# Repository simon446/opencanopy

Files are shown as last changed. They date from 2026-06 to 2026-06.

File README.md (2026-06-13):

# OpenCanopy — Tabletop Automated Pepper Grower

Open-source, zero-config, offline-first tabletop grow unit for a single hot pepper plant.

OpenCanopy is an open-hardware project: a compact, living-room-friendly appliance that keeps one hot
pepper plant healthy indoors with minimal user involvement. It combines a broad-spectrum horticultural
LED, automated pump irrigation with soil-moisture sensing, climate/VPD monitoring, water-safety
interlocks, and a simple LED status interface — all driven by deterministic, fully local **Rust**
firmware (`no_std`, `esp-hal`) on an ESP32-S3.

📖 **Docs site:** <https://simon446.github.io/opencanopy/> · 🧩 **Contributing:** [`CONTRIBUTING.md`](CONTRIBUTING.md) · ⚖️ **Licensing:** [`LICENSES/`](LICENSES/)

The project is built **work item by work item**, organized by engineering discipline. The full
engineering plan and the per-discipline work-item breakdown live in [`plan/`](plan/) — the design
source for the build (engineering spec + work items), tracked alongside the implementation in this repo.

## Project status

- **Repository skeleton, licensing, scope lock, risk register, and CI are in place** (the Project &
  Repo track is complete) — every discipline has a home and quality gates run on each PR.
- **Firmware language: Rust** (`no_std` + `esp-hal`), with a host-testable `control` crate and
  `cargo fmt`/`clippy`/`test` gates in CI.
- The remaining discipline tracks (plant science, firmware, electronics, mechanical, validation, docs)
  follow the work-item breakdown in `plan/`. A spec design review (§23) added pre-order modeling and
  bench-characterization gates and an n=2 parallel grow trial.

## Where things live

| What | Path |
|---|---|
| Documentation (rendered) | <https://simon446.github.io/opencanopy/> |
| Documentation (source) | [`docs/`](docs/) — requirements, scope, risk register, guides |
| Contributing & workflow | [`CONTRIBUTING.md`](CONTRIBUTING.md); issue/PR templates in [`.github/`](.github/) |
| Licensing (per asset type) | [`LICENSES/`](LICENSES/) |
| Implementation subtrees | [`firmware/`](firmware/), [`electronics/`](electronics/), [`mechanical/`](mechanical/), [`validation/`](validation/), [`scripts/`](scripts/) |
| Work items & engineering spec (design source) | [`plan/`](plan/) — engineering spec + per-discipline work items |

## Scope

- **In V1:** one plant, fixed hot-pepper profile, dimmable full-spectrum LED with automated schedule,
  substrate moisture sensing, automated pump watering, reservoir-level + leak safety, temp/humidity
  sensing with VPD, circulation fan, 5-LED status interface, local deterministic firmware, and open
  hardware/firmware/CAD with simulation, hardware-in-loop, and grow-trial validation.
- **Not in V1:** camera/AI plant diagnosis, cloud control, automatic pH/EC dosing, multi-plant
  support, required mobile app, or AC mains inside the unit.

See [`docs/scope.md`](docs/scope.md) for the locked non-goals and [`docs/product-requirements.md`](docs/product-requirements.md)
for the locked physical/hardware envelope.

## Repository layout

The standard open-hardware structure is in place; each subtree has a README describing its purpose:

- `firmware/` — Rust workspace: `control/` (host-testable `no_std` logic), `controller/` (`esp-hal`
  binary), `sim/`, `hil/`.
- `electronics/` — KiCad PCB, wiring, BOM, and electrical verification.
- `mechanical/` — CAD/STEP/STL, drawings, and print settings.
- `docs/` — requirements, scope, risk register, and the guides that ship with V1.
- `validation/` — test plans, measurements, and grow-trial records.
- `scripts/` — tooling (`bom_check.py` §16.3 grow-light gate, `stl_check.py`, calculators).

Full layout: spec §14 (in `plan/`).

## Release gate

V1 is tagged only when the acceptance criteria in the V1 spec (§21, in `plan/`) are all met, as proven
by the Validation & QA track — including an **n=2 parallel grow trial** (design-review decision, §23).

## License

Per-asset open-source licensing — **Apache-2.0** firmware/scripts, **CERN-OHL-S v2** hardware/mechanical,
**CC BY 4.0** docs. See [`LICENSES/`](LICENSES/) and its [mapping note](LICENSES/README.md).

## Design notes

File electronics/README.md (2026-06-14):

# electronics/

PCB, wiring, BOM, and electrical verification for OpenCanopy. Owned by the **Electronics** track
(spec §7, §11, §16).

## Layout

- `pcb/` — custom controller board (designed with the headless tscircuit flow; KiCad retired — [ECO-002](analysis/ECO-002-pcb-toolchain.md)).
  - `netlist/` — **the schematic as data**: `controller_netlist.py` (source of truth — every part +
    pin-level net + ERC checker), generated `controller.net` (optional interchange) and `controller-netlist.csv`.
  - `programmatic/` — **headless code→PCB→Gerbers** flow (tscircuit): the generator, the board, the
    per-subsystem render blocks, and `out/` (draft Gerbers/PnP/BOM + KiCad-PCB bridge + previews).
  - `3d-models/` — checked-in STEP/WRL models of off-the-shelf parts (e.g. the WS2812B-2020 status LED) for mechanical CAD.
  - `fabrication/` — fab notes + stackup (the fab package itself lives in `programmatic/out/`).
- `wiring/` — system harness.
  - `wiring-diagram.svg` — full system wiring diagram.
  - `harness-table.csv` — connector/pin/wire/gauge harness table.
  - `connector-spec.md` — chosen connectors + mating cable-side parts (handoff for mechanical).
- `bom/` — bill of materials.
  - `bom.csv` — primary BOM (must satisfy the §16 constraint list).
  - `alternates.csv` — approved alternate parts.
  - `component-sourcing.md` — real buyable picks for pump / grow light / status LEDs / cables, with
    3D-model sources and the firmware/mechanical/project flags they raise.
- `test/` — electrical verification.
  - `bringup.md` — bench bring-up procedure (WI-EE-08).
  - `pcb-verification.md` — trace/current and thermal verification report (WI-EE-06).
  - `hil-fixture.md` — HIL fixture design + automated fault-test matrix (WI-EE-08).
  - `poc-logs/` — breadboard PoC bench-log templates (WI-EE-01).
- `analysis/` — engineering design/analysis artifacts.
  - thermal budget model + script (WI-EE-10), power budget (WI-EE-02), component PoC plan (WI-EE-01),
    schematic capture + pin map (WI-EE-03), PCB layout design (WI-EE-04) + `design-rules.md` (net
    classes/DRC), status-LED board (WI-EE-09), trace-width calculator, `ECO-001-fan-removal.md`.
    The board layout is generated from the `pcb/netlist/` netlist by the tscircuit flow + these docs.

## Key constraints

ESP32-S3 controller, 24 VDC external certified PSU, electronics in the upper dry bay, locking/keyed
connectors. The grow-light BOM entry must carry real photometric/thermal/electrical data (spec §16.3);
`scripts/bom_check.py` enforces this in CI.

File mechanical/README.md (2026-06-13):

# mechanical/

Frame, bays, mounts, and printable parts for OpenCanopy. Owned by the **Mechanical** track
(spec §8, §12).

## Layout

- `cad/` — design source.
  - `source/` — **parametric build123d model** (Python); see `cad/source/README.md`
    for toolchain + how to regenerate. This is the dimensional authority.
  - `step/` — neutral STEP exports (full assembly + every module), regenerated by
    `cad/source/build.py`.
- `stl/` — printable geometry, regenerated from source.
  - `printable/` — release-quality, manifold STLs intended for end users.
  - `prototypes/` — tolerance coupons / experimental prints.
  - `assembly/` — placed meshes (every part in its assembly position, coarse) used
    by `render.py` and `collision_check.py`; not for printing.
- `drawings/` — orthographic assembly views, generated by `cad/source/drawings.py`.
- `cad-verification-checklist.md` — §12.1 checklist, numbers computed by `verify.py`.
- `bom-mechanical.csv` — mechanical bill of materials (pot, reservoir, frame, …).
- `print-settings.md` — material/zone + slicer settings (PETG/ASA/ABS per §16.2).
- `fit-tests.md` — tolerance-coupon results; feeds calibrated clearances to `params.py`.
- `alpha-build.md` — assembly procedure + alpha build log (M5-09).

## Regenerate artifacts

```bash
.venv-cad/bin/python mechanical/cad/source/build.py            # STEP + STL + placed meshes
.venv-cad/bin/python mechanical/cad/source/verify.py           # §12.1 numbers
.venv-cad/bin/python mechanical/cad/source/collision_check.py  # FCL worst-case interference sim
.venv-cad/bin/python mechanical/cad/source/render.py           # full-assembly sketch renders
.venv-cad/bin/python mechanical/cad/source/drawings.py         # SVG views
.venv-cad/bin/python scripts/stl_check.py --dir mechanical/stl # CI manifold gate
```

The interference sim (`collision_check.py`) runs FCL on the real models with a
configurable printer error margin — see `tolerance-analysis.md`. Multi-angle sketch
renders of the whole build are published to the docs site (`docs/mechanical-build.md`,
images in `docs/assets/renders/`) and refreshed by the Pages CI.

## Key constraints

Open-frame appliance within the **locked 480 × 320 × 700 mm envelope** (see
`docs/product-requirements.md`): electronics in an isolated upper dry bay, water in
the bottom wet bay, removable 10 L pot and 4 L reservoir, leak tray, fan guard, and
stainless fasteners near water (spec §8, §16.2, §17). The model asserts the envelope
and the "water fails downward / electronics live upward" zone separation (§6.2) on
every build.

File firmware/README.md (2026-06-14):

# firmware/

Firmware for the OpenCanopy controller (ESP32-S3), written in **Rust** (`no_std`, `esp-hal`), plus its
host-side simulation and hardware-in-the-loop (HIL) harnesses. Owned by the **Firmware** track. See
spec §9–§10.

This is a Cargo **workspace**. The core control logic is a platform-agnostic `no_std` crate that builds
and unit-tests on the host with stable Rust — no ESP32 and no Xtensa toolchain required to validate
rules (spec §9.1, §10.1). Only the on-target `controller` binary needs the Espressif toolchain.

## Layout

- `Cargo.toml` — workspace manifest (added by the Firmware track, [WI-FW-01](../plan/work-items/02-firmware/WI-FW-01-project-build.md)).
- `rust-toolchain.toml` — pins the Espressif Rust channel (installed via `espup`).
- `.cargo/config.toml` — default target `xtensa-esp32s3-none-elf` + `espflash` runner.
- `control/` — **no_std, platform-agnostic** control logic: state machine, moisture monitor, light,
  climate, LED status, plant profile, and the `hal.rs` sensor/actuator/clock **traits** (the hardware
  seam). V1 is passive (no pump) and fan-less (ECO-003/ECO-001) — the grow LED is the only actuator.
  Builds and `cargo test`s on the host with stable Rust. Has **no** `esp-hal` dependency.
  - `src/`, `tests/`.
- `controller/` — **no_std `esp-hal` binary** for the ESP32-S3; provides concrete trait
  implementations binding `control` to real peripherals.
  - `src/` — `main.rs` plus `sensors/`, `actuators/`, `drivers/`.
- `sim/` — host scenario runner that drives the real `control` crate through simulated trait impls
  (no hardware). See `sim/README.md`.
  - `src/`, `scenarios/`, `models/`.
- `hil/` — hardware-in-the-loop fixtures and procedures for testing on real boards. See `hil/README.md`.
  - `fixtures/`.

## Toolchain

- **Host tests / sim:** stable Rust — `cargo test -p control`, `cargo fmt --check`, `cargo clippy`.
- **On-target build:** install the esp channel with `espup`, then `cargo build` (target set in
  `.cargo/config.toml`); flash/monitor with `espflash`. Xtensa is not on upstream stable Rust, which is
  why host-testable logic is isolated in `control/`.

## Principles (spec §9.1, §10.1)

Control rules are deterministic and offline-first, validated in simulation before any PCB exists, then
re-validated on hardware via HIL. The state machine and fault priorities (§9.3) are encoded as
compiler-checked Rust types. The grow LED (the only actuator) must fail safe (off) on reset/brownout.
Optional Wi-Fi/MQTT telemetry (§9.11) lives behind a default-off Cargo feature, never required for control.

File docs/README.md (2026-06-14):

# docs/

Project documentation for OpenCanopy. These are the human-readable references that ship with V1.

Per spec §14.1, this subtree holds:

| File | Owner track | Purpose |
|---|---|---|
| `product-requirements.md` | Project & Repo | Locked physical envelope and hardware decisions (the design contract). |
| `scope.md` | Project & Repo | V1 scope and explicit non-goals. |
| `risk-register.md` | Project & Repo | Engineering and safety risks, owners, and mitigations. |
| `plant-profile-hot-pepper.md` | Plant Science | Lifecycle stages, setpoints, DLI, watering, VPD, nutrients. |
| `safety.md` | Documentation | Water/electrical, thermal, food-contact, child/pet safety. |
| `assembly.md` | Documentation | Build/assembly guide. |
| `calibration.md` | Documentation | Moisture and pump calibration procedure. |
| `operation.md` | Documentation | Day-to-day operation and grow guide. |
| `troubleshooting.md` | Documentation | Common faults and fixes. |
| `validation-plan.md` | Validation & QA | Dry/wet/grow-trial acceptance plan. |
| `led-status-legend.md` | Documentation | Front-panel LED meaning (state + blink pattern). |
| `maintenance.md` | Documentation | User and developer maintenance schedule. |
| `references.md` | Documentation / Plant Science | Cited sources behind the design decisions. |

The minimum documentation set required before a V1 tag is listed in spec §14.3.

## Engineering & design references (rendered)

Published design docs with renders, one per hardware track:

| Doc | Track | What |
|---|---|---|
| [`electronics-design.md`](electronics-design.md) | Electronics | Controller board: per-subsystem schematics + 3D/board renders, safety design, connectors, BOM, the headless netlist→Gerbers flow. |
| [`mechanical-build.md`](mechanical-build.md) | Mechanical | v1 product-model renders (CAD), joints, conduit, collision/physics checks. |
| [`firmware-api.md`](firmware-api.md) | Firmware | Pointer to the published Rust API docs (`/api`). |

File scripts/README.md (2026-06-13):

# scripts/

Project tooling and calculators for OpenCanopy (spec §14.1). Plain Python, no heavy dependencies, so
they run locally and in CI.

| Script | Purpose | Used by |
|---|---|---|
| `bom_check.py` | Validate `electronics/bom/bom.csv`; fail if a grow light lacks the §16.3 required fields. | CI (WI-PS-06), Electronics |
| `dli_calculator.py` | Convert PPFD ↔ DLI for a photoperiod; estimate delivered PPFD from fixture PPF. **Delivered (`--selftest` in CI).** | Plant Science (WI-PL-02) |
| `pump_calibration.py` | Derive pump on-time ↔ delivered-volume calibration. | Firmware / Validation |
| `moisture_calibration.py` | Map raw capacitive readings to dry/wet calibration points. | Firmware / Validation |
| `log_parser.py` | Parse exported device logs into analyzable form. | Validation |

`bom_check.py` ships with the project-setup track; `dli_calculator.py` ships with Plant Science
(WI-PL-02). The remaining scripts are stubbed by their owning tracks. CI invokes `bom_check.py` and
`dli_calculator.py --selftest` on every PR.

> A reproducible **photometric delivery model** (the §23 DR-01 pre-order PPFD/DLI gate, WI-PL-06) lives
> with the validation track at
> [`validation/ppfd-measurements/model/`](../validation/ppfd-measurements/model/), not here.

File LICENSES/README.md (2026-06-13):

# Licensing

OpenCanopy is multi-licensed **by asset type** — firmware, hardware/mechanical, and documentation
each carry a different open-source license, as recommended in spec §14.2 and locked in §20. Do **not**
collapse these into a single root `LICENSE`; the licenses differ deliberately.

## License files

| File | License | SPDX identifier |
|---|---|---|
| [`firmware-license.txt`](firmware-license.txt) | Apache License 2.0 | `Apache-2.0` |
| [`hardware-license.txt`](hardware-license.txt) | CERN Open Hardware Licence v2 — Strongly Reciprocal | `CERN-OHL-S-2.0` |
| [`docs-license.txt`](docs-license.txt) | Creative Commons Attribution 4.0 International | `CC-BY-4.0` |

## Subtree → license map

This is the authoritative mapping. Every tracked subtree falls under exactly one license.

| Path / asset | License | SPDX |
|---|---|---|
| `firmware/` (all source, tests, sim, HIL) | Apache-2.0 | `Apache-2.0` |
| `scripts/` (project tooling) | Apache-2.0 | `Apache-2.0` |
| `electronics/` (PCB: KiCad source, Gerbers, BOM, wiring) | CERN-OHL-S v2 | `CERN-OHL-S-2.0` |
| `mechanical/` (CAD source, STEP, STL, drawings) | CERN-OHL-S v2 | `CERN-OHL-S-2.0` |
| `docs/` (all documentation) | CC BY 4.0 | `CC-BY-4.0` |
| `README.md`, `CONTRIBUTING.md`, top-level prose | CC BY 4.0 | `CC-BY-4.0` |
| `validation/` test plans, reports, measurement data | CC BY 4.0 | `CC-BY-4.0` |
| `validation/photos/`, captured `validation/logs/` | CC BY 4.0 — **see condition below** | `CC-BY-4.0` |

### Why these three (and why CERN-OHL-S for hardware)

- **Firmware → Apache-2.0:** permissive, with an explicit patent grant; standard for embedded
  firmware that others may vendor into their own builds.
- **Hardware + mechanical → CERN-OHL-S v2 (Strongly Reciprocal):** the project lead's locked default
  (§20). Strong reciprocity keeps derived board/enclosure designs open. The project lead may override
  to `CERN-OHL-P` (permissive) or `CERN-OHL-W` (weakly reciprocal) per asset — record any such
  override here and in the risk register before it takes effect.
- **Documentation → CC BY 4.0:** attribution-only reuse of the written guides.

## Photos and logs — privacy condition

`validation/photos/` and any captured device/operator logs in `validation/logs/` are released under
**CC BY 4.0 only after personally identifying information has been removed** (faces, reflections,
people in frame, home/network identifiers, location metadata, EXIF GPS, account names, IPs/MACs).
Until that scrub is done, a given photo or log is **not** licensed for redistribution — strip the PII
first, then it falls under CC BY 4.0 like the rest of `validation/`.

## Applying licenses in new files

- Source files (`firmware/`, `scripts/`): add an SPDX header, e.g. `// SPDX-License-Identifier: Apache-2.0`.
- Hardware/mechanical exports where a header is impractical: the subtree mapping above governs.
- Docs: covered by the `docs/` mapping; no per-file header required.

This file is the REUSE-style mapping note required by WI-PS-02. If the directory layout grows, update
the table above so every subtree still resolves to exactly one license.

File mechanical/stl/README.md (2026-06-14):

<!-- SPDX-License-Identifier: CERN-OHL-S-2.0 -->
# mechanical/stl — ⚠️ superseded (build123d arched model)

> **These STLs are from the SUPERSEDED design** — the build123d arched-frame model with a
> **pump**, **fan**, separate **pot**, in-base **electronics dry bay**, and **cable/tube channel**.
> They do **not** reflect the current V1, which was redesigned by
> [ECO-003](../../docs/ECO-003-v1-redesign.md) to a **two-pillar** form with **electronics in the top
> block** and **passive self-watering (no pump, no fan)**.

The authoritative current geometry is the OpenSCAD source
`mechanical/cad/opencanopy_tabletop_pepper_v1_block_model.scad` (per-part STLs are exported by
`mechanical/cad/render_block.py` into the gitignored `mechanical/cad/exports/parts/`, all manifold;
geometry audited by `mechanical/cad/audit.py`).

**Stale here (do not print for V1):** `frame.stl`, `fan-mount.stl`, `pump-clip.stl`,
`electronics-dry-bay*.stl`, `pot*.stl`, `cable-channel.stl`, `light-mount.stl` (arched-era),
`leak-tray.stl`, etc., under `assembly/` and `printable/`.

**Still valid:** the **tolerance coupons** under `prototypes/` are generic fit coupons (heat-set,
screw boss, snap-fit, slot/rail) — most carry over; new coupons (pillar↔base socket, PCB standoff,
block body/lid seam) are added per [WI-ME-08](../../plan/work-items/04-mechanical/WI-ME-08-tolerance-alpha-build.md).

**Follow-up (later CAD pass):** regenerate the printable part STLs from the OpenSCAD model and
replace the superseded files here. Until then, treat everything except `prototypes/` as historical.

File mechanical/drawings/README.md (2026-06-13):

# Drawings

Orthographic assembly references, generated from the parametric model by
`../cad/source/drawings.py` (regenerate after any geometry change). Solid lines are
visible edges; dashed grey are hidden edges.

| File | View | Looking |
|---|---|---|
| `assembly-front.svg` | Front elevation | along +Y (the open user-facing front) |
| `assembly-right.svg` | Right elevation | along −X |
| `assembly-top.svg` | Plan / top | along −Z |

These show the locked **480 × 320 × 700 mm** envelope, the vertical stack (dry bay
on top, grow zone with light + fan, pot on its tray, wet bay at the bottom) and the
clearances tabulated in `../cad-verification-checklist.md`.

Dimensioned manufacturing drawings of individual printed parts are not maintained as
separate files — the parametric source (`../cad/source/`) and the STEP exports
(`../cad/step/`) are the dimensional authority.

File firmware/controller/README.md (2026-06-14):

# controller/ — ESP32-S3 on-target binary

The bare-metal firmware that runs on the device. It is a **thin binding layer**: every control rule
lives in the platform-agnostic [`control`](../control) crate (host-tested, spec §10.2). This binary
only initializes esp-hal peripherals, wires them to `control`'s `hal.rs` traits, and runs the 5-min
control loop.

## Build / flash (requires the Espressif toolchain)

Xtensa is **not** on upstream stable Rust. Install the esp channel once, then build from this
directory (the target + flasher come from `controller/.cargo/config.toml`):

```sh
cargo install espup espflash
espup install            # installs the `esp` toolchain pinned by controller/rust-toolchain.toml
cd firmware/controller
cargo build --release    # -> xtensa-esp32s3-none-elf
cargo run   --release    # flash + serial monitor via espflash
cargo build --release --features telemetry   # optional Wi-Fi/MQTT (default-off, §9.11)
```

Host crates (`control/`, `sim/`) do **not** need any of this — run `cargo test` from `firmware/`.

## Why a standalone package (excluded from the workspace)

esp-hal/esp-wifi only build for `xtensa-esp32s3-none-elf` and pull from crates.io. Keeping this crate
out of the host workspace (`firmware/Cargo.toml` `exclude`) means the host unit/sim suite never tries
to resolve or build them — it stays offline-clean on stable Rust (WI-FW-01 acceptance).

## Status / ownership

The module structure and control-loop sequencing are fixed here (`main.rs`, `sensors/`,
`actuators/`, `drivers/`). The esp-hal peripheral construction and the **pin map** are finalized
during electronics bring-up ([WI-EE-08](../../plan/work-items/03-electronics/WI-EE-08-bringup-hil.md));
binding method bodies marked `TODO(WI-EE-08)` are completed against real hardware there. V1 is passive
(no pump, ECO-003): the grow LED is the only actuator and is forced off on reset by the RWDT/brownout
detector armed in `drivers::Platform` (and the LED driver's own enable default).

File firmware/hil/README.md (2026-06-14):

# firmware/hil/

Hardware-in-the-loop (HIL) test harness for OpenCanopy. Runs the firmware on a real ESP32-S3 board
with instrumented actuators and simulated/sensed inputs, to verify behavior that pure simulation
cannot fully guarantee. Owned by the **Firmware** track, coordinated with **Electronics** (spec §10.4).

## Layout

- `fixtures/` — bench fixtures, harness adapters, signal injectors, and instrumentation configs that
  connect a board under test to controlled stimuli (e.g. forced leak signal, reservoir-low signal,
  abnormal-moisture signal, over-temperature injection).

## Purpose

V1 is passive (no pump, ECO-003) and fan-less (ECO-001): the grow LED is the only actuator and the
firmware **monitors and warns**. HIL proves the safety-critical paths on real silicon: the LED forced
off on reset/brownout, over-temperature LED cut-back (the grow LED is the only thermal lever), and the
warning/LED-status correctness for leak/overflow, reservoir-low, abnormal-moisture, and sensor-fault
under injected faults. HIL pass is a V1 release gate (spec §21 *Electronics*/*Firmware*).

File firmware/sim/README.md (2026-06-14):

# firmware/sim/

Host-side simulation of the OpenCanopy grow loop. Runs entirely on a developer machine and in CI —
no ESP32-S3 and no wet hardware required. Owned by the **Firmware** track (spec §10.3).

This is a host Rust crate that drives the **real `control` crate** (not a reimplementation) through
host implementations of its `hal.rs` traits, against software models of the plant, soil moisture,
reservoir, and thermal behavior, then asserts the control logic reacts correctly. Scenarios run as
`cargo test` on stable Rust — no Xtensa toolchain needed.

## Layout

- `src/` — the simulation runner and host trait implementations that feed the `control` crate.
- `scenarios/` — the scenarios exercised in CI (V1 is passive — monitor + warn, no pump), e.g.:
  - passive wick holds moisture → normal grow,
  - reservoir drain → LOW_WATER refill warning,
  - wick failure → MOISTURE_LOW with a full reservoir,
  - leak/overflow → LEAK_DETECTED warning (Water + System red),
  - canopy over-temperature → LED derate,
  - simultaneous faults → correct fault priority ordering.
- `models/` — the plant/soil/thermal/reservoir models the scenarios drive.

## Acceptance

Simulation scenarios are a CI gate (spec §10.5, §21 *Firmware*): a PR that breaks a scenario fails CI.

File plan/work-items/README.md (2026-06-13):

# Work Items

This directory decomposes the [V1 Engineering Specification](../tabletop_pepper_grower_v1_spec_v1_1.md)
into **self-contained work items**, grouped by the specialist who owns each one.

Each work item is a single markdown file that can be picked up independently. It states its
objective, the spec sections it implements, concrete deliverables, acceptance criteria, and
dependencies on other work items. The goal: a specialist (or an agent) can open one file and
start working without re-reading the full 2000-line spec.

## How to read a work item

Every file follows the same header:

| Field | Meaning |
|---|---|
| Track | Owning specialist discipline |
| Milestone | Mapping back to spec §15 milestone (M0–M7), where applicable |
| Depends on | Work items that must land first |
| Spec refs | Sections of the spec this item implements |

Statuses are tracked inline (`Not started` / `In progress` / `Blocked` / `Done`). Treat the
checkbox lists as the definition of done.

## Tracks

| Track | Folder | Owner profile | Summary |
|---|---|---|---|
| Project & Repo | [`00-project-setup/`](00-project-setup/) | Project lead / DevOps | Repo skeleton, licensing, scope lock, risk register, CI |
| Plant Science | [`01-plant-science/`](01-plant-science/) | Horticulturist / CEA specialist | Lifecycle profile, light/DLI, watering, VPD, nutrients |
| Firmware | [`02-firmware/`](02-firmware/) | Embedded software engineer | Control logic, simulator, safety state machine, logging |
| Electronics | [`03-electronics/`](03-electronics/) | EE / PCB designer | Breadboard PoC, schematic, PCB, harness, bring-up, HIL |
| Mechanical | [`04-mechanical/`](04-mechanical/) | Mechanical / CAD engineer | Frame, bays, mounts, routing, print tolerances |
| Validation & QA | [`05-validation-qa/`](05-validation-qa/) | Test / QA engineer | Dry/wet runs, thermal, acoustic, fault injection, grow trial |
| Documentation | [`06-documentation/`](06-documentation/) | Technical writer | README, safety, assembly, calibration, grow guide |

## Suggested sequencing

The tracks are intentionally parallelizable, but there is a critical path:

```
00 Project setup ──► 01 Plant science ──► 02 Firmware (sim) ──┐
                                                              ├─► 05 Validation ──► Grow trial
03 Electronics (PoC ──► schematic ──► PCB ──► bring-up) ───────┤
04 Mechanical (CAD ──► alpha build) ──────────────────────────┘
06 Documentation runs continuously, finalized before release.
```

- **Plant science** must lock setpoints before firmware control logic is meaningful.
- **Pre-order modeling gate** (M1.5: [WI-PL-06](01-plant-science/WI-PL-06-photometric-model.md) +
  [WI-EE-10](03-electronics/WI-EE-10-thermal-budget-model.md)) must pass before the grow light is
  ordered or CAD is frozen — see spec §23 (DR-01).
- **Firmware simulation** (`02-firmware`) can be fully validated before any PCB exists, but its models
  must be re-parameterized from measured bench data
  ([WI-QA-09](05-validation-qa/WI-QA-09-bench-characterization.md), §23 DR-02) before gating a live
  grow loop.
- **Electronics PoC** can run in parallel with plant science; the custom PCB waits on PoC results.
- **Validation** integrates the outputs of firmware + electronics + mechanical.
- **Grow trial** is the final gate and depends on a fully integrated unit; a surrogate full-loop
  shakedown ([WI-QA-10](05-validation-qa/WI-QA-10-surrogate-shakedown.md), §23 DR-03) precedes it.

## Release gate

V1 is tagged only when the acceptance criteria in spec §21 are all met. The
[validation track](05-validation-qa/) owns proving each one.

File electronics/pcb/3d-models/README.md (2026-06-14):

<!-- SPDX-License-Identifier: CC-BY-4.0 -->
# 3D models (for mechanical CAD + EDA)

Checked-in **STEP / WRL** models of the off-the-shelf parts, so the mechanical track can drop real
geometry into the enclosure CAD and any EDA tool can render the board. Tool-neutral (STEP = solid for
CAD, WRL = mesh for fast render).

## Models

| Part | BOM ref | Files | Size | Source |
|---|---|---|---|---|
| **WS2812B-2020** addressable LED (status indicators) | `LED_STATUS` (×5 on PCB2) | `WS2812B-2020_C965555.step`, `.wrl` | 2.0 × 2.0 × 0.8 mm | LCSC **C965555** / EasyEDA, fetched with [`easyeda2kicad`](https://github.com/uPesy/easyeda2kicad.py) |

The WS2812B-2020 STEP is a real BREP solid (SolidWorks AP214 origin, ~300 faces), not a placeholder
box — it matches the `LED-SMD_4P-L2.0-W2.0-H0.8` datasheet outline. There are **5** of these on the
front-panel status board (PCB2, [WI-EE-09](../../analysis/WI-EE-09-status-led-board.md)); mechanical
also needs the **PCB2 outline** to place them behind the diffuser.

## Provenance & licensing

The WS2812B-2020 model is the **manufacturer/EasyEDA-provided geometry** for LCSC part `C965555`,
retrieved via `easyeda2kicad`. It is redistributed here only to build/visualise this open-hardware
design; the model geometry remains the vendor's and is subject to LCSC/EasyEDA's model terms — treat it
as a reference/visualisation model, not a re-licensable asset. (If a fully license-clean model is
needed, the 2.0 × 2.0 × 0.8 mm 4-pad outline is trivial to regenerate from the datasheet.)

Reproduce:

```sh
pip install easyeda2kicad
python3 -m easyeda2kicad --full --lcsc_id=C965555 --output=WS2812B-2020
```

## What's *not* here (and why)

- **Grow light (`LED_PANEL`)** — it's an **LED board/module**, not a discrete diode we place, so its
  geometry is the **board outline + heatsink** from the chosen vendor (a rectangle for CAD), paired
  with the WI-ME-05 heatsink — not a single-diode model.
- **Pump, LED driver (LDD-H), connectors** — big-geometry items mechanical designs around; their STEP
  sources are listed in [`../../bom/component-sourcing.md`](../../bom/component-sourcing.md) §5 (Mean Well
  STEP download, TOPSFLO on request, JST/Amass via SnapEDA). Add them here the same way as they're picked.

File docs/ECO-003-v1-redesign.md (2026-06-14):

<!-- SPDX-License-Identifier: CC-BY-4.0 -->
# ECO-003 — V1 redesign: two-pillar form, electronics-to-top, pump removal (passive watering)

**Type:** Engineering Change Order (product-wide; mechanical/maintainer-originated record)
**Date:** 2026-06-14
**Status:** Approved (maintainer) · Mechanical reconciliation **complete** · cross-track hand-offs **open**
**Owning track:** Mechanical · **Cross-track:** Firmware, Electronics, Plant Science, Validation/QA, Project & Repo
**Supersedes:** the arched-frame product model and the base-electronics two-zone layout.
**Relation:** sibling to [ECO-001](../electronics/analysis/ECO-001-fan-removal.md) (fan removal — folded in here).
**Spec touch:** §3.3/§3.5 (envelope, controls), §4.1/§4.2 (scope), §6.2 (zones), §7.2 (pump), §7.4 (fan),
§7.5 (sensors), §9.4/§9.5 (irrigation/safety), §17.1 (water/elec), §20 — changes to **locked** requirements;
see §"Cross-track hand-offs" for the spec/risk-register updates the Project track must ratify.

## 1. Decision

OpenCanopy V1 is redesigned to a **two-pillar Scandinavian tabletop form** and converted from active
to **passive self-watering**. Maintainer-approved 2026-06-14. The change has four parts:

1. **Form factor.** Replace the arched side-frame + bridge with a **low integrated base**, **two
   vertical wooden pillars**, and a **slim top LED block**. The grow light is centred over the plant.
2. **Electronics to the top.** The controller + LED driver move **out of the base into the top block**
   as a **small 1.6 mm PCB**, encapsulated inside the block on standoff bosses, with a **USB-C input**
   through the block rear face. The base has **no electronics bay**.
3. **No pump (passive watering).** The pump and all pump support (driver, connector, flow/lockout
   logic, daily/runtime caps, pump-fail-off) are **removed**. Watering is **passive semi-hydro**: a
   base reservoir + a removable slotted/perforated grow insert with a capillary wick path. The system
   **monitors and warns** (low water, abnormal moisture); it does not actuate water.
4. **No fan.** Confirms and folds in [ECO-001](../electronics/analysis/ECO-001-fan-removal.md).

**Retained, unchanged:** electronics and water are physically separated; open-frame / non-enclosed;
external low-voltage DC power (now USB-C, no AC mains inside); one pepper plant; 50–80 W dimmable
full-spectrum LED; no screen, no user controls; open-source CAD/HW/FW/docs.

**Changed locked values:** wet/dry separation is now **TOP (electronics) vs BOTTOM (water)** instead of
an in-base wall; **reservoir 4 L → 6 L**; the **separate 10 L pot** becomes an **integrated removable
grow insert**; **status LEDs 5 → 4** (Water, Moisture, Light, System — no Climate LED with no fan/active
climate control); power input **24 VDC barrel → USB-C** (pending electrical validation, §3 below).

## 2. Why passive (clarified intent)

The pump was the active irrigation actuator. Passive semi-hydro (reservoir + wick + slotted insert with
an air gap) is simpler, silent, has **no flood failure mode**, removes a whole class of safety logic
(leak→pump-lockout, fail-off, daily/runtime caps), and suits a single tabletop plant. The trade-off is
that passive delivery must keep a mature Carolina-Reaper-class plant adequately watered between manual
refills — this is **not yet proven** and is gated on a grow trial (see §5 open items, and Open Q below).

## 3. The things that could bite (flagged, not closed here)

- **USB-C power for a 50–80 W LED.** USB-C PD can supply up to 100 W (240 W EPR), but 50–80 W must be
  deliberately engineered (PD negotiation, cable/connector rating, driver input). **Mechanical only
  reserves the connector space + routing**; the **electronics track must validate feasibility** or
  fall back to a DC barrel input. (Open Q2.)
- **Passive watering adequacy.** Whether wick + slotted insert keeps root-zone moisture correct for a
  mature plant is a **plant-science** question (wick area, media choice, air gap, refill cadence vs the
  6 L reservoir). (Open Q3.) Mitigation: validate in the n=2 grow trial; design reserves space for an
  optional pump/aeration retrofit module if passive underperforms.
- **Reservoir stagnation** with no circulation: inert nutrients, opaque tank, documented refill/clean
  cadence (plant-science / docs).

## 4. Mechanical reconciliation (done in this change — mechanical track)

| Artifact | Change |
|---|---|
| `mechanical/cad/opencanopy_tabletop_pepper_v1_block_model.scad` | Full rewrite to base + 2 pillars + top block + raised grow insert + 6 L reservoir; PCB encapsulated in the block (1.6 mm, mounting holes, USB-C rear port); no pump/fan/base-bay/in-base-wall. |
| `mechanical/cad/render_block.py`, `audit.py` | New parts/views; **geometry audit CLEAN** (no interpenetration > 80 mm³, none floating); LED centred over the grow module (offset 0.0/0.0). |
| `docs/mechanical-build.md`, `docs/fastening.md` | New architecture, pillar joints, encapsulated-PCB note. |
| `plan/work-items/04-mechanical/WI-ME-01..08` | Re-scoped: assembly (two-pillar), pot→insert, electronics-bay (obsolete in base), wet-bay (passive reservoir, no pump mount), cable (sensor leads up a pillar), fan-mount (obsolete, ECO-001), light-mount (passive heatsink, ECO-001), tolerance/alpha. |
| `mechanical/stl/` (build123d arch/pump/fan parts) | Flagged **superseded** (see `mechanical/stl/README.md`); to be regenerated from the OpenSCAD model in a later CAD pass. |
| `docs/product-requirements.md`, `docs/scope.md`, `docs/risk-register.md` | Updated by mechanical under this ECO with maintainer (Project & Repo) sign-off; see change-control trail in the risk register. |

## 5. Cross-track hand-offs (NOT changed here — flagged to owners)

- **Firmware:** remove pump/irrigation actuation. `WATERING`, `PUMP_FAULT`, `PUMP_TIMEOUT` states and
  the leak→pump-lockout / daily-runtime-cap / pump-fail-off logic become **N/A**. New behaviour is
  **monitor + warn**: `LOW_WATER`, `MOISTURE_LOW`, `MOISTURE_HIGH`, `SENSOR_FAULT`, `OVER_TEMP_LED`,
  `MAINTENANCE`. The fan channel/`FAN_FAULT` are already N/A (ECO-001). Affects
  `firmware/control/src/irrigation_controller.rs`, `app_state.rs`, `safety_controller.rs`, and the sim
  scenarios/tests. (Firmware track.)
- **Electronics:** remove the **pump driver + pump connector + pump current-sense** from the BOM/netlist
  (mark DNP-optional if a retrofit provision is wanted, as the fan was in ECO-001); **validate USB-C PD
  for the 50–80 W LED** or specify a DC input. Update power budget, harness, schematic, PCB. (Electronics
  track.) Note: the just-completed controller netlist/BOM still carry the pump.
- **Plant Science:** convert `docs/watering-model.md` from **active pump watering** to **passive
  semi-hydro** (wick area, media, air gap, refill cadence vs 6 L, stagnation mitigation); confirm a
  raised insert with ~5 L effective media + 6 L reservoir suffices for a mature plant, or set the
  documented trade-off. (Plant-science track — single source of truth for plant targets.)
- **Validation / QA:** drop pump flow-rate / timeout / fail-off / leak-lockout-of-pump and fan
  PWM/acoustic tests; add **passive wicking, reservoir drawdown, refill-cadence, root-zone moisture
  stability, overflow, wet/dry-separation leak, insert removal/clean, water-level calibration** tests.
  (QA track.)
- **Project & Repo:** ratify the locked-value changes in the **main spec** (`plan/…spec_v1_1.md`
  §7.2 pump, §7.4 fan, §6.2 zones, §3.3 envelope, §3.5 controls, §7.5 sensors, §9.4/§9.5) — this ECO and
  the updated `product-requirements.md`/`scope.md`/`risk-register.md` are the record; the engineering
  spec text is the Project track's to update.

## 6. Open questions (documented, non-blocking)

1. Does the low base fit 6 L reservoir + the insert without looking too tall? **Resolved in CAD:** the
   insert is a **raised planter** above a 135 mm base; reservoir is 6.6 L gross.
2. **Is USB-C PD sufficient for the 50–80 W LED**, or is a DC barrel required? — electronics.
3. **Does passive watering hold root-zone moisture for a mature chili?** — plant-science + grow trial.
4. Should the reservoir be removable, or is fill/drain service enough? — currently fill-from-top +
   insert lift-out for cleaning.
5. Pillars: real wood dowels vs printed faux-wood vs composite (affects the threaded-insert joint).
6. Fixed vs adjustable light height — **fixed** for V1 (clean form); adjustable is a V2 question.

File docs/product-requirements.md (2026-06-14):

# OpenCanopy V1 — Product Requirements (Locked)

**Status:** Locked (M0-04, M0-05) · **Owner:** Project & Repo track · **Spec refs:** §3.3, §4.1, §4.2, §20

This document freezes the physical envelope and the core hardware decisions for OpenCanopy V1. It is
the **design contract** every other track designs against. The values below are decisions, not
ranges-for-discussion.

> **Change control:** Any change to a locked value after this point requires a corresponding entry in
> [`risk-register.md`](risk-register.md) and sign-off from the Project & Repo track. Downstream tracks
> may treat these numbers as fixed.
>
> **🔄 REDESIGN — [ECO-003](ECO-003-v1-redesign.md) (2026-06-14, maintainer-approved).** V1 moved to a
> **two-pillar Scandinavian form** with **electronics in the top LED block** and **passive
> self-watering (no pump, no fan)**. Locked-value changes ratified here: wet/dry separation is now
> **top (electronics) vs bottom (water)**; **reservoir 4 L → 6 L**; the separate **10 L pot → an
> integrated removable grow insert**; **status LEDs 5 → 4**; power input **24 VDC barrel → USB-C**
> (pending electrical validation). Change-control trail: see [`risk-register.md`](risk-register.md).

---

## 1. Physical envelope (locked)

Two build variants are defined. **Compact V1 is the default build**; the full-yield variant is an
optional larger configuration. Every dimension below is a hard limit, not a target band.

| Parameter | Compact V1 (default) — committed nominal | Compact V1 — allowed band | Full-yield variant — hard max |
|---|---:|---:|---:|
| Width (W) | **480 mm** | 450–500 mm | **550 mm** |
| Depth (D) | **320 mm** | 300–350 mm | **400 mm** |
| Height (H) | **680 mm** | 650–750 mm | **850 mm** |
| Grow media (integrated insert) | **≈5 L effective** | 4–8 L | TBD (full-yield) |
| Reservoir volume | **6 L** (6.6 L gross modelled) | 5–7 L | **7 L** |
| Useful canopy footprint | 240–300 mm W × 170–210 mm D | — | 300–400 mm W × 220–300 mm D |
| Plant count | **1** | — | **1** |
| Wet electronics exposure | **None** (electronics are in the top block) | — | **None** |

**Hard maximums (no build may exceed):** W ≤ 550 mm, D ≤ 400 mm, H ≤ 850 mm, reservoir ≤ 7 L.

**Rationale for the committed compact nominals (ECO-003):**

- **Passive self-watering** replaces the pumped pot: a **6 L base reservoir** feeds a **removable grow
  insert** (slotted/perforated, semi-hydro, wick contact). Reservoir raised to 6 L to lengthen the
  unattended refill interval without a pump.
- The grow insert is a **raised planter** above a low (135 mm) base, so the base holds the reservoir at
  ≤ 130 mm visible height. Effective media (~5 L) is a documented trade-off vs the old 10 L pot,
  **gated on the grow trial** (risk-register R2/R9; ECO-003 Open Q3).
- H nominal 680 mm: two pillars place the LED with generous clearance over the raised insert.

## 2. Architecture & safety envelope (locked — ECO-003)

- **Top/bottom layout (current):** the **electronics live in the top LED block** (small 1.6 mm
  controller+driver PCB, encapsulated, USB-C input); the **base is a single wet zone** (6 L passive
  reservoir + removable grow insert). Water and electronics are separated by **geography (top vs
  bottom)**, not an in-base wall — no water path can reach the electronics (§17.1). Only sealed
  low-voltage sensor leads + status-LED light pipes touch the base, via a grommet at a pillar.
- **No AC mains inside the unit.** Power is **external low-voltage DC via USB-C** (pump-class loads
  removed; LED is the only significant load). USB-C-PD-vs-DC-barrel feasibility for 50–80 W is an
  open electrical-validation item (ECO-003 Open Q2); no mains inside, ever (§17.1).
- **Open-frame / non-enclosed default** (§3.6): not a sealed grow chamber. Room temperature is assumed
  **22–25 °C**. Firmware does **not** maintain an independent air-temperature setpoint. No humidifier,
  heater, refrigeration, or sealed chamber in V1.

## 3. Controller & user interface (locked)

| Decision | Locked value |
|---|---|
| MCU | **ESP32-S3** (dev module or custom PCB module) |
| Display | **None** — no LCD/e-ink in V1 |
| User controls | **Hidden service/reset control only** (factory reset / grow-cycle reset / test mode); no user-facing screen |
| Status interface | **4 front status LEDs** (Water, Moisture, Light, System); state by color **and** blink pattern + position (do not rely on color alone). *(Was 5 — the Climate LED is dropped: no fan / no active climate control; climate warnings fold into System. ECO-003.)* |
| Connectivity | **Optional, offline-first.** **USB-C** input doubles as the serial/dev interface; web/MQTT/Home Assistant telemetry allowed but **must not be required** |

## 4. Actuators (locked — ECO-003)

The **only actuator in V1 is the grow light.** Watering is passive; there is no fan.

| Subsystem | Locked decision |
|---|---|
| Pump | **REMOVED (ECO-003).** V1 is **passive self-watering** — a base reservoir feeds a removable slotted grow insert by capillary wicking. No pump, no pump driver/connector, no watering actuation; the firmware **monitors and warns** (low water / abnormal moisture) only. (A pump/aeration retrofit may be provisioned but is not populated.) |
| Fan | **REMOVED ([ECO-001](../electronics/analysis/ECO-001-fan-removal.md)).** No fan in V1; the LED runs on a passive heatsink under natural convection. |
| Light | **50–80 W dimmable full-spectrum white** horticultural LED for compact V1; **100 W only** for the full-yield variant. Dimmable via PWM/0–10 V matching the selected driver. The only significant electrical load (drives the USB-C-vs-barrel question, Open Q2). |

**Grow-light data requirement (§16.3):** a candidate light may be specified in the BOM **only** if it
provides actual power draw, a PPF/PPFD map, dimming method, full-spectrum/horticultural spectrum data,
thermal mounting information, and electrical certification/safety data where available. Lights
advertising only lumens, "equivalent watts," or vague "red/blue plant lamp" claims are rejected.
This is enforced in CI by `scripts/bom_check.py`.

## 5. Sensor set (locked)

Required V1 sensors (§7.5, §20): **temp/RH** (SHT31/SHT4x-class, I²C), **soil/media moisture**
(capacitive, corrosion-resistant, replaceable), **reservoir low-level**, and **leak/flood**
(overflow). VPD is **computed** from temp/RH, not separately sensed. *(Fan tach removed — no fan,
ECO-001. No pump current-sense — no pump, ECO-003.)*

## 6. Expansion headers (provisioned, not populated)

V1 PCB/mechanical may include connectors/pads for future modules but must **not** be blocked on them
(§4.3): camera, PAR/light sensor, load cell under pot, EC sensor, pH sensor, CO₂ sensor, e-ink status,
external telemetry. None of these are functional in V1 — see [`scope.md`](scope.md).

## 7. Traceability

| Locked item | Spec source |
|---|---|
| Footprint, grow insert, reservoir | §3.3, §20; ECO-003 |
| MCU / display / controls | §3.5, §7.1, §20 |
| Light (pump + fan removed) | §7.2–§7.4, §16, §20; ECO-003, ECO-001 |
| Sensor set | §7.5–§7.6, §20 |
| Open-frame / power / top-bottom zones | §3.6, §7.8, §17; ECO-003 |
| Expansion headers | §4.3 |

## 8. Rationale & research basis

These decisions are grounded in extension/research guidance (full list in
[`references.md`](references.md); design detail in spec §2 and §5). The key "whys":

- **Open-frame, room 22–25 °C, no enclosure.** A 22–25 °C indoor room is adequate for hot peppers, so
  the cost/complexity of a sealed, actively climate-controlled chamber isn't justified for V1; the
  device manages only LED heat, airflow, watering, and warnings (§2.3, §3.6). [R4, R5]
- **Integrated grow insert + passive semi-hydro (ECO-003).** Root volume still drives plant health, so
  the insert is sized as large as the low base allows (~5 L effective, raised) feeding from a 6 L
  reservoir; adequacy for a mature plant is grow-trial-gated (risk-register R2/R9). [R7, R8, R9]
- **Light specified in DLI/PPFD, broad-spectrum white, dimmable.** Fruiting peppers are high-light:
  the target is DLI ≈ 20–25 mol·m⁻²·day⁻¹ and ≥ ~400 µmol·m⁻²·s⁻¹ PPFD across the canopy, achievable
  in a tabletop footprint only with a constrained canopy, a real PPFD map, and pruning. Lumens / "plant
  lamp" claims are rejected (§2.1, §7.2, §16.3). [R1, R2, R3, R14]
- **Passive self-watering, no pump (ECO-003).** Steady moisture supports fruit retention and reduces
  blossom-end rot, but waterlogging harms roots — a **wicking semi-hydro** insert with an air gap aims
  for steady moisture **without a pump** (so there is no flood/overwater failure mode); the system
  monitors and warns instead of actuating. Root-zone moisture adequacy is the key grow-trial question
  (risk-register R3/R10). [R5, R8, R15, R16]
- **VPD computed from temp/RH, not RH alone.** VPD is the physiologically meaningful driver of
  transpiration and disease pressure (§5.4). [R13]

See [`references.md`](references.md) for the cited sources and [`scope.md`](scope.md) for what these
constraints deliberately exclude.

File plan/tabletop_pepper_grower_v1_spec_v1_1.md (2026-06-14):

# Tabletop Automated Pepper Grower — V1 Engineering Specification

**Document status:** Draft v1.1 — revised for compact open-frame tabletop target; **circulation fan removed 2026-06-14** (all tracks agreed)  
**Target crop:** Carolina Reaper / superhot pepper, treated as a hot-pepper profile for *Capsicum chinense* with environmental targets informed by broader pepper (*Capsicum* spp.) and controlled-environment agriculture research.  
**Target product:** Open-source, compact, non-enclosed tabletop indoor grow unit for one productive pepper plant.  
**Primary interface:** Zero-config appliance with LED status indicators.  
**Revision summary:** Default footprint reduced; default architecture changed to open-frame/non-enclosed; 22–25°C room operation accepted.  
**Non-goals for V1:** Camera AI, cloud plant health, pH/EC auto-dosing, active room-temperature control, mobile app dependency, multiple species profiles, high-yield commercial production.

---

## 1. Executive Summary

V1 is a compact, visually pleasant, open-source tabletop grow system for a single hot pepper plant, optimized for Carolina Reaper-class plants. It should be engineerable as a public repository containing:

- Mechanical CAD, STL/STEP files, print settings, and assembly drawings.
- Electronics schematics, PCB files, wiring diagrams, and hardware verification procedures.
- Firmware with deterministic control rules, simulation tests, hardware abstraction tests, and hardware-in-loop verification.
- Plant-growing rules embedded as a fixed pepper profile so the user does not need to configure species or growth recipes.
- Validation plans covering software, electronics, pump/irrigation behavior, thermal behavior, noise, mechanical fit, water safety, and real grow trials.

Revision v1.1 incorporates these product decisions:

- The default unit is **open-frame / non-enclosed**, assuming normal indoor room temperature around 22–25°C.
- The default footprint is reduced; a larger “full-yield” variant remains documented for builders who prefer maximum plant size over table fit.
- **The circulation fan is removed** (2026-06-14, agreed across mechanical, electronics, and firmware). The open frame relies on passive convection; there is no forced airflow or active humidity control, and derating/cutting the grow LED is the only lever the firmware has over canopy temperature. Climate sensing is retained for monitoring and warnings only.

The system should prioritize:

1. **Reliable plant growth over gadget features.**
2. **Safety around water and electricity.**
3. **Simple visible status.**
4. **Open, testable, reprogrammable architecture.**
5. **A living-room/table-friendly aesthetic.**

V1 should not ship with camera-based plant diagnosis. That can become a V2 expansion module after the basic light, water, sensor, and safety loops are proven. The most useful intelligence for V1 is not “AI,” but well-tested feedback loops around light schedule, substrate moisture, reservoir state, temperature, humidity/VPD, pump safety, and fault detection.

---

## 2. Research Basis and Key Design Decisions

### 2.1 Core plant facts used by this spec

The system targets a warm-season pepper. Relevant research and extension guidance support these facts:

- Peppers are warm-season crops. They grow poorly in cool conditions and fruit set is reduced at temperature extremes.
- Multiple extension sources report best pepper production around warm day conditions and mild nights, with fruit-set problems when days exceed roughly 90°F / 32°C or nights are too cold or too warm.
- Consistent moisture is important for flower/fruit retention and blossom-end-rot reduction, but waterlogging harms roots.
- Container-grown plants dry quickly and need frequent but not excessive watering.
- Peppers perform best around soil/potting media pH 6.0–6.8 in soil/container media.
- For controlled-environment grow lighting, DLI and PPFD are the primary engineering quantities, not lumens.
- Fruiting peppers should be treated as high-light plants. V1 should target a DLI around 20–25 mol·m⁻²·day⁻¹ at fruiting if heat and fixture capability allow, and it should be able to deliver at least ~400 µmol·m⁻²·s⁻¹ PPFD across the useful canopy area.
- A broad-spectrum white horticultural LED with sufficient blue and red content is preferred over a decorative or “blurple-only” LED for a tabletop living-space product.

### 2.2 Main sources used

The design values in this document are based on the following sources and their cited extension/research guidance:

| ID | Source | Used for |
|---|---|---|
| R1 | Virginia Tech Extension, “Calculating and Using Daily Light Integral (DLI)” — https://pubs.ext.vt.edu/SPES/spes-720/spes-720.html | DLI concept, PPFD/DLI relationship, 400–700 nm PAR framing |
| R2 | University of Missouri Extension, “Controlled Environment Agriculture: Understanding Grow Lights” — https://extension.missouri.edu/publications/g6987 | CEA grow-light selection, LED considerations, system-level light planning |
| R3 | Oklahoma State University Extension, “LED Grow Lights for Plant Production” — https://extension.okstate.edu/fact-sheets/led-grow-lights-for-plant-production | PPFD and DLI ranges; high-light crop framing |
| R4 | Oklahoma State University Extension, “Pepper Production” — https://extension.okstate.edu/fact-sheets/pepper-production | Pepper temperature, fruit-set constraints, soil pH |
| R5 | Michigan State University Extension, “How to Grow Peppers - Part 2” — https://www.canr.msu.edu/resources/how_to_grow_peppers_part_2 | Pepper day/night temperatures, moisture, blossom drop |
| R6 | University of Minnesota Extension, “Growing peppers” — https://extension.umn.edu/vegetables/growing-peppers | Seed starting, germination warmth, moisture, watering practice |
| R7 | University of Minnesota Extension, “Fertilizing and watering container plants” — https://extension.umn.edu/managing-soil-and-nutrients/fertilizing-and-watering-container-plants | Container moisture behavior and fertilizer caution |
| R8 | Illinois Extension, “Watering | Container Gardens” — https://extension.illinois.edu/container-gardens/watering | Container watering, avoiding waterlogged roots, avoiding full dry-out |
| R9 | Oregon State University Extension, “Grow your own peppers” — https://extension.oregonstate.edu/catalog/ec-1227-grow-your-own-peppers | Container size, drainage, greenhouse/container pepper guidance |
| R10 | Ohio State University Ohioline, “Growing Peppers in the Home Garden” — https://ohioline.osu.edu/factsheet/hyg-1618 | pH, drip/soaker watering, wet-leaf disease avoidance |
| R11 | Oklahoma State University Extension, “Electrical Conductivity and pH Guide for Hydroponics” — https://extension.okstate.edu/fact-sheets/electrical-conductivity-and-ph-guide-for-hydroponics | Hydroponic pH/EC reference values for peppers |
| R12 | University of Missouri Extension, “Hydroponic Nutrient Solutions” — https://extension.missouri.edu/publications/g6984 | Nutrient solution management, pH/EC monitoring limitations and calibration |
| R13 | Michigan State University Extension, “Why should greenhouse growers pay attention to vapor-pressure deficit and not relative humidity?” — https://www.canr.msu.edu/news/why_should_greenhouse_growers_pay_attention_to_vapor_pressure_deficit_and_n | VPD logic and humidity disease/transpiration framing |
| R14 | Liu et al., “Effects of LED Light Quality on the Growth of Pepper Seedlings and Development after Transplanting,” Agronomy, 2022 — https://www.mdpi.com/2073-4395/12/10/2269 | Pepper seedling response to blue/UV-A/far-red light quality |
| R15 | Michigan State University Extension, “Blossom end rot: Understanding a perennial problem” — https://www.canr.msu.edu/news/blossom_end_rot_understanding_a_perennial_problem | Blossom-end-rot relationship to calcium transport and inconsistent water |
| R16 | Ohio State University Small Farm Team, “Blossom End Rot of Tomatoes and Peppers” — https://u.osu.edu/gofarmohio/2022/07/15/blossom-end-rot-of-tomatoes-and-peppers/ | Blossom-end-rot stress and dry/wet soil swings |
| R17 | PuckerButt Pepper Company, Carolina Reaper growing guide — https://puckerbuttpeppercompany.com/blogs/insights/the-complete-guide-to-growing-your-very-first-carolina-reaper-pepper-plant | Carolina Reaper-specific seed-starting and temperature context |

### 2.3 Important limitation

This is not a commercial greenhouse crop plan. It is a small indoor device plan. Therefore:

- The DLI target is ambitious but can be approached in a compact tabletop footprint only if the canopy area is constrained, the LED has a real PPFD map, and the plant is pruned/trained.
- The default compact geometry trades some maximum yield for table fit and visual acceptability. This is acceptable for V1 because the target is credible indoor fruiting, not commercial yield.
- The default design is not enclosed. It does not actively heat or cool the room, and (with the fan removed) it does not manage airflow. It only manages LED heat contribution, watering, and warning states.
- A 22–25°C indoor room is acceptable for hot pepper growth. It is not severe enough to justify an enclosure in V1. Germination may still benefit from a removable heat mat or external warm-start method.
- The system must support dimming and heat management rather than running a high-power LED blindly.

---

## 3. Product Definition

### 3.1 Product goal

Build an open-source tabletop grow system that can maintain a single hot pepper plant indoors with minimal user involvement.

The user should only need to:

1. Fill the reservoir.
2. Add nutrients/fertilizer manually according to a simple written schedule.
3. Prune/support the plant when necessary.
4. Harvest fruit.
5. Clean the reservoir and pump/filter periodically.
6. Reset the grow cycle when starting a new plant.

### 3.2 Intended user

- Technical hobbyist, open-source hardware builder, engineer, maker, or advanced indoor gardener.
- Comfortable assembling electronics and 3D-printed/mechanical parts.
- Does not want to tune a dashboard daily.
- Wants a living-room/table-friendly object rather than a black grow tent.

### 3.3 Physical footprint target

| Dimension | Compact V1 target | Hard max / full-yield variant |
|---|---:|---:|
| Width | 450–500 mm | 550 mm |
| Depth | 300–350 mm | 400 mm |
| Height | 650–750 mm | 850 mm |
| Pot volume | 8–10 L | 12–19 L if yield is prioritized |
| Reservoir | 2.5–4 L | 4–6 L |
| Useful canopy footprint | 300–400 mm W × 220–300 mm D | 400–450 mm W × 300–350 mm D |
| Wet electronics exposure | None | None |
| Plant count | 1 | 1 |

### 3.4 Visual design target

V1 should look like a small furniture object or tabletop appliance, not like lab equipment.

Recommended visual language:

- White or matte neutral frame.
- Light wood/bamboo/oak-colored front trims.
- Hidden wiring.
- Translucent LED-status diffuser strip.
- Open front for plant visibility.
- Rear/top service access.
- Bottom reservoir not visibly industrial.
- No LCD/e-ink display in the default v1 design.

### 3.5 Primary UX

The system should be usable with no app and no normal controls.

Visible user interface:

| Indicator | Position | Normal | Warning | Fault |
|---|---|---|---|---|
| Water | Front LED 1 | Green steady | Amber slow pulse | Red blink |
| Moisture | Front LED 2 | Green steady | Amber pulse | Red blink |
| Light | Front LED 3 | Green when active / dim when sleeping | Amber if dimmed due to heat | Red if LED fault |
| Climate | Front LED 4 | Green steady | Amber if hot/dry/humid | Red if critical |
| System | Front LED 5 | Green heartbeat | Amber maintenance | Red fault |

Design requirements:

- Do not rely on color alone. Blink pattern and LED position must convey state.
- Optional hidden service button is allowed for factory reset / grow-cycle reset / test mode.
- No user-facing screen in V1.
- Optional serial/USB development interface is allowed.
- Optional web/MQTT/Home Assistant telemetry is allowed but must not be required.

### 3.6 Open-frame / non-enclosed default

V1 should be an **open-frame appliance**, not a sealed grow chamber.

Design consequences:

- Room temperature is assumed to be 22–25°C.
- The firmware does not attempt to maintain an independent air-temperature setpoint.
- V1 has no circulation fan: the open frame relies on passive convection, and there is no forced airflow, heat dispersion, or active cooling below ambient.
- LED intensity is the only meaningful heat source the device can control, and derating/cutting it is the only lever the device has over canopy temperature.
- The system may derate the LED if canopy temperature rises, but it should not overcomplicate temperature control.
- No humidifier, heater, refrigeration module, or sealed chamber is included in V1.
- A removable seed-starting dome or separate heat mat may be documented for germination, but it is not part of the core appliance.

Engineering interpretation: 22–25°C room conditions are close enough to published pepper production ranges to proceed without an enclosure. The likely penalties are slower germination without bottom heat and possibly less optimal fruit set if nights remain warm, but these are not severe enough to justify enclosure complexity in V1.

---

## 4. V1 Scope and Non-Scope

### 4.1 V1 includes

- One plant.
- Fixed hot-pepper profile.
- Broad-spectrum horticultural LED with dimming.
- Automated light schedule.
- Soil/substrate moisture sensing.
- Automated pump watering.
- Reservoir-level sensing.
- Temperature/humidity sensing.
- VPD calculation (monitor + LED-derate response; no fan in V1).
- Leak/flood safety sensor.
- LED status interface.
- Local deterministic firmware control.
- Open-source firmware.
- Open-source PCB and wiring.
- Open-source mechanical design.
- Simulation tests.
- Hardware verification.
- Grow validation protocol.

### 4.2 V1 excludes

- Camera plant health analysis.
- Cloud AI plant diagnosis.
- Plant species auto-ID.
- Automatic pH dosing.
- Automatic EC/nutrient dosing.
- Multi-plant support.
- Commercial yield optimization.
- Voice assistant dependency.
- Required mobile app.
- AC mains inside the grow unit.

### 4.3 Optional V1 expansion headers

Include connectors/pads for future modules, but do not block V1 on them:

- Camera module.
- PAR/light sensor.
- Load cell under pot.
- EC sensor.
- pH sensor.
- CO₂ sensor.
- E-ink status module.
- External telemetry module.

---

## 5. Plant-Growing Specification

### 5.1 Growth stages

The firmware should implement a built-in hot-pepper lifecycle profile. No user species selection is required.

| Stage | Approx. duration | Trigger | Main objective |
|---|---:|---|---|
| S0 Germination | 0–21 days | Grow-cycle reset | Warm, moist media until emergence |
| S1 Seedling | 21–56 days | Time-based | Compact growth, avoid stretch |
| S2 Vegetative | 56–100 days | Time-based / plant size | Strong canopy and root system |
| S3 Flowering | 100–140 days | Time-based / first flower observed manually optional | Stable moisture, pollination support |
| S4 Fruiting/ripening | 140+ days | Time-based | Stable water, high light, avoid heat stress |
| S5 Maintenance/overwinter | optional | Manual dev setting only | Lower light/water, survival mode |

Because V1 has no camera, stage detection is time-based. The hidden service button can reset the grow cycle. This is not considered “configuration”; it is equivalent to starting a timer when a new plant is inserted.

If the build is intended only for purchased transplants, the firmware can skip S0/S1 by flashing a `TRANSPLANT_PROFILE=true` build flag. The public default should include all stages.

### 5.2 Environmental targets

The table below gives biological targets. Because V1 is **non-enclosed**, firmware should treat temperature and RH as monitored conditions, not as actively controlled setpoints. Light and watering remain actively controlled.

| Stage | Preferred air temp | Acceptable open-room assumption | RH target | VPD target | DLI target | Photoperiod | PPFD target at canopy |
|---|---:|---:|---:|---:|---:|---:|---:|
| Germination | 26–30°C media | Room 22–25°C acceptable but slower; optional external heat mat recommended | 65–80% | n/a | 0–6 after emergence | 0–16 h | 0–100 µmol/m²/s |
| Seedling | 23–27°C day, 18–22°C night | 22–25°C acceptable | 60–75% | 0.5–0.9 kPa | 8–12 | 16 h | 140–210 µmol/m²/s |
| Vegetative | 22–28°C | 22–25°C ideal/acceptable | 55–75% | 0.7–1.2 kPa | 14–20 | 16 h | 245–350 µmol/m²/s |
| Flowering | 22–27°C day, 18–22°C night preferred | 22–25°C acceptable; avoid LED raising canopy above 28–30°C | 55–70% | 0.8–1.2 kPa | 18–24 | 16 h | 315–420 µmol/m²/s |
| Fruiting | 22–27°C day, 18–22°C night preferred | 22–25°C acceptable; prioritize stable moisture and high light | 55–70% | 0.8–1.3 kPa | 20–25 | 16 h | 350–435 µmol/m²/s |

Formula:

```text
DLI = PPFD × photoperiod_hours × 0.0036
PPFD = DLI / (photoperiod_hours × 0.0036)
```

Example for fruiting:

```text
Target DLI: 23 mol·m⁻²·day⁻¹
Photoperiod: 16 h
Required average PPFD: 23 / (16 × 0.0036) ≈ 399 µmol·m⁻²·s⁻¹
```

### 5.3 Temperature behavior in open-frame mode

Firmware should monitor temperature and use LED derating to avoid adding avoidable heat stress. V1 has no fan, so derating/cutting the LED is the only thermal lever; it cannot cool the plant below room temperature.

| Condition | Action |
|---|---|
| <16°C air | Climate LED amber; do not increase watering due to slow uptake |
| 16–20°C | Accept; possible slower growth; no active heating in V1 |
| 20–25°C | Normal open-room operating band |
| 25–28°C | Normal if transient; watch for a rising trend during lights-on |
| 28–30°C | Climate LED amber if sustained; prevent additional LED heat if rising |
| 30–32°C | Reduce LED 20–40% if LED heat is contributing |
| >32°C | Climate LED red; reduce LED 40–70%; pump only if substrate is dry; log heat fault |
| >35°C | Critical over-temp; LED off or minimum; system fault if sustained |

Fruit-set protection:

- Avoid sustained canopy temperatures above 32°C. Published pepper guidance repeatedly flags poor fruit set/blossom drop around this range and above.
- Constant 22–25°C indoor room temperature is acceptable for V1 and does not justify an enclosure.
- Flowering may improve if nights naturally fall closer to 18–22°C, but this is an optimization, not a V1 requirement.
- Avoid watering decisions based only on high temperature; always verify substrate moisture.

### 5.4 Humidity and VPD behavior

Use VPD as the internal decision variable, but expose only climate status to the user.

Basic VPD logic:

| VPD | Interpretation | Action |
|---:|---|---|
| <0.4 kPa | Air too humid / low transpiration | Climate amber warning; avoid watering unless dry |
| 0.5–1.2 kPa | Normal productive range | Normal control |
| 1.2–1.6 kPa | Dry air / high transpiration | Watch moisture, shorter dryback allowed |
| >1.6 kPa | Stress risk | Alert if persistent; avoid LED heat increase |

RH guardrails:

| RH | Action |
|---:|---|
| >85% sustained | Climate amber/red; disease-risk warning (no fan in V1 — prompt the user to ventilate the room) |
| 70–85% | Accept if short-term; warn if sustained |
| 55–70% | Preferred flowering/fruiting range |
| <40% | Dry-air warning if VPD high |

V1 has no fan and no humidification. The climate logic only **warns** on humidity and adjusts light/watering conservatively; it has no actuator that can change the air directly.

### 5.5 Substrate and potting media

Recommended V1 medium:

- High-quality peat/coco-based potting mix.
- Perlite or similar aeration amendment.
- Drainage-capable pot.
- Optional internal wicking mat/reservoir, but not a fully sealed no-drainage pot.

Hard constraints:

- Pot volume: 8–10 L compact V1 baseline. Use 12–19 L for the optional full-yield variant. Do not go below 8 L for a Reaper-class plant unless the project explicitly accepts ornamental/low-yield behavior.
- Pot must drain into a controlled tray or internal basin.
- Pot must be removable without disconnecting electronics.
- Pot must not sit in stagnant water unless intentionally designed as a self-watering planter with an air gap.
- Avoid native garden soil indoors due to drainage, compaction, and pest issues.

### 5.6 Watering target

V1 should not try to keep the substrate constantly wet. It should maintain moist-but-aerated conditions with controlled dryback.

Control target:

| State | Meaning | Action |
|---|---|---|
| Too wet | Sensor above wet threshold for long period | Block watering; amber moisture LED |
| Target | Within range | No action |
| Dry | Below dry threshold | Dose water in pulses |
| Critically dry | Well below dry threshold | Dose water with stricter observation; red/amber LED if not recovering |

Watering windows:

- Prefer watering during the light period.
- Prefer first 60–70% of the light period.
- Avoid routine watering in the last 2 hours before lights-off.
- Emergency watering is allowed at any time if critically dry.
- Do not water if reservoir is low.
- Do not water if leak sensor is active.
- Do not water if pump-fault state is active.
- Do not water continuously; use pulses and remeasure.

Initial defaults:

| Stage | Dry threshold | Wet threshold | Pulse size target | Recheck delay |
|---|---:|---:|---:|---:|
| Seedling | calibrated 35% VWC-equivalent | calibrated 55% | 20–50 mL | 15–20 min |
| Vegetative | calibrated 30% | calibrated 55% | 50–150 mL | 20–30 min |
| Flowering | calibrated 35% | calibrated 60% | 75–200 mL | 20–30 min |
| Fruiting | calibrated 35% | calibrated 60% | 100–250 mL | 20–30 min |

These percentages are not raw sensor percentages. They are normalized wet/dry calibration units. The firmware must never assume raw capacitive ADC readings correspond directly to volumetric water content without calibration.

### 5.7 Nutrients

V1 should not include automatic nutrient dosing. It should document a manual feeding schedule.

Recommended default documentation:

- Use a complete pepper/tomato fertilizer suitable for container vegetables.
- Avoid over-fertilization.
- Start with low-strength feeding after seedlings are established.
- Increase potassium-supported fruiting fertilizer only after flowering/fruit set.
- Include a monthly flush/refresh recommendation if using soluble fertilizer and drainage exists.
- Optional: use slow-release container fertilizer plus plain water in reservoir for simplest operation.

Hydroponic/DWC is not the recommended V1 baseline because pH/EC management adds significant calibration and maintenance burden. If a variant is hydroponic, require pH/EC manual testing and separate documentation.

### 5.8 pH and EC

For the default potting-mix/drip V1:

- No continuous pH/EC sensors.
- Include optional manual test guidance.
- Target potting media pH: 6.0–6.8.
- Avoid repeated heavy fertilization without drainage/flush.

For optional hydroponic variant:

- Nutrient solution pH: 5.5–6.0.
- Root-zone pH: approximately 6.0–6.5.
- Pepper EC reference: 0.8–1.8 mS/cm from OSU hydroponic table, with caution that commercial greenhouse pepper guidance can run higher depending on stage/system.
- Require weekly pH/EC meter calibration if pH/EC automation is ever added.

### 5.9 Pollination and pruning

V1 should not mechanically pollinate, and with no fan it does not provide assisted airflow. It relies on manual pollination and includes grow-guide instructions:

- Gently shake plant or tap flowers several times per week during flowering.
- Keep the plant in a room with gentle natural air movement, not strong wind.
- Support branches as fruit load increases.
- Prune only enough to maintain clearance and passive airflow.
- Keep fruit from touching the LED.
- Leave enough leaf canopy to protect fruit from intense light and heat.

Optional V2 feature:

- Tiny vibration motor mounted to frame or trellis, run briefly at midday during flowering. Not required in V1.

---

## 6. System Architecture

### 6.1 High-level architecture

```text
External certified AC/DC power brick
        |
        v
24 VDC input into dry upper electronics bay
        |
        +--> fuse / protection / power switch
        |
        +--> LED driver / dimmer --> grow light
        |
        +--> DC/DC 12 V rail --> pump (only if a 12 V pump is used)
        |
        +--> DC/DC 5 V rail --> sensors / logic
        |
        +--> 3.3 V rail --> MCU
        |
        v
MCU control board
        |
        +--> temp/humidity sensor
        +--> capacitive moisture sensor
        +--> reservoir level sensor
        +--> leak sensor
        +--> pump MOSFET/driver
        +--> LED dimming output
        +--> front status LEDs
        +--> optional UART/USB/debug
```

### 6.2 Physical zone model

```text
TOP / UPPER DRY ZONE
- Controller PCB
- LED driver
- Power distribution
- Status LED board
- Optional comms/camera expansion
- Service access

MIDDLE GROW ZONE
- Plant canopy
- Pot
- LED fixture above
- Temp/humidity sensor shielded from direct LED heat
- Moisture probe routed into pot

BOTTOM WET ZONE
- Removable water reservoir
- Pump
- Intake filter
- Water-level sensor
- Leak tray/sensor
- Drainage/overflow path
```

Design rule:

> Water may fail downward. Electronics must live upward and sideways from the wet path.

### 6.3 Control philosophy

V1 control is deterministic:

```text
time-of-day + plant age + sensor inputs + safety states
→ light/pump outputs
→ LED user feedback
```

No cloud decision-making is required. Cloud AI is explicitly deferred.

---

## 7. Hardware Specification

### 7.1 Controller selection

Recommended V1 MCU:

| Option | Recommendation | Reason |
|---|---|---|
| ESP32-S3 | Preferred | Good firmware ecosystem (C/C++ **and** Rust via `esp-hal`), Wi-Fi/BLE, enough RAM/IO, future camera compatibility |
| ESP32-C6 | Acceptable | Wi-Fi 6 + BLE + Thread/Zigbee/Matter path |
| ESP32-C3 | Acceptable low-cost | Wi-Fi/BLE, fewer IO |
| Raspberry Pi Pico W | Acceptable | Simple control, Wi-Fi, but less integrated CEA ecosystem |
| ESP32-H2 only | Not preferred | No Wi-Fi; better as Zigbee/Thread node |

V1 should standardize on **ESP32-S3** unless Matter/Thread is a hard requirement. This leaves camera expansion possible without adding a second compute board later.

### 7.2 Light requirements

This is the most important hardware component.

#### Required light type

Use a **full-spectrum white horticultural LED bar or panel** with enough blue and red content. Avoid decorative “plant lamps” with no PPFD map. Avoid blurple-only fixtures for a living-room tabletop design unless a white-light cover mode is added.

Minimum fixture requirements:

| Parameter | Minimum compact V1 | Preferred compact V1 / full-yield headroom |
|---|---:|---:|
| Electrical power | 40–50 W dimmable | 50–80 W dimmable; 100 W only for larger variant |
| PPF | 100 µmol/s | 140–220 µmol/s |
| PPE | 2.2 µmol/J | ≥2.5 µmol/J |
| Dimming | PWM or 0–10 V | 0–10 V isolated or logic PWM |
| Spectrum | Broad white horticultural | White + 660 nm deep red; ≥10% blue content |
| PPFD at canopy | 350–450 µmol/m²/s average | 400–550 µmol/m²/s average if heat allows |
| Uniformity | ≥0.6 min/avg | ≥0.7 min/avg |
| Driver | Remote or thermally isolated | Remote driver in upper dry bay |
| Thermal protection | Required | NTC or driver thermal foldback |
| Ingress protection | Splash-resistant preferred | IP54+ or conformal protected board |
| Color rendering | Not critical for plants | Pleasant enough for living area |

#### Canopy area assumption

V1 useful canopy target:

```text
Compact canopy width: 300–400 mm
Compact canopy depth: 220–300 mm
Compact canopy area: ~0.07–0.12 m²
Full-yield variant canopy area: ~0.12–0.16 m²
```

If targeting 450 µmol/m²/s across 0.10 m²:

```text
Required delivered PPF ≈ 450 × 0.10 = 45 µmol/s
```

Because optics, height, side losses, canopy shape, and non-uniformity reduce delivered photons, fixture PPF should be much higher than the delivered target. A 140–220 µmol/s fixture is a practical compact range for dimmed operation with headroom. A larger 220–250 µmol/s fixture belongs in the optional larger/full-yield variant.

#### Light mounting

- LED must be mounted above canopy.
- Height should be adjustable if possible.
- Minimum clearance from mature canopy: 150 mm unless PPFD/thermal measurements prove safe.
- Thermal path must not dump heat into electronics.
- Driver heat should be isolated from plant canopy and plastic parts.
- Use mechanical secondary retention so the light cannot fall into the plant/wet area.

### 7.3 Pump requirements

Recommended V1 pump type:

**Brushless DC submersible centrifugal pump**, 12 V or 24 V.

Why this over peristaltic for V1:

| Pump type | Pros | Cons | V1 decision |
|---|---|---|---|
| Brushless submersible centrifugal | Quiet, cheap, low maintenance, continuous-rated, long life | Must stay submerged, less precise dosing, can clog | **Preferred V1** |
| Peristaltic | Precise, self-priming, no wetted pump internals, dry-run tolerant | Noisier, tubing wear, lower flow, more expensive | Optional precision variant |
| Diaphragm | Self-priming, decent pressure | Pulsing noise, vibration | Not preferred |
| Solenoid valve + gravity | Quiet, simple if elevated tank | Requires elevated reservoir, leak risk | Not preferred |

Required pump constraints:

| Parameter | Target |
|---|---:|
| Voltage | 12 V or 24 V DC |
| Flow rating | 80–240 L/h nominal; do not oversize for a small tabletop pot |
| Head height | ≥0.8 m, preferred ≥1.0 m |
| Noise | ≤30 dBA at 1 m after mounting, target ≤25 dBA |
| Power | <5 W preferred, <10 W max |
| Intake | Removable filter/screen |
| Mount | Rubber isolated or suspended in reservoir |
| Dry-run protection | Firmware timeout + reservoir sensor |
| Dose repeatability | ±25% acceptable after calibration |
| Tubing | 4/6 mm or 6/8 mm silicone/PVC |
| Outlet | Drip ring or single emitter at substrate surface |
| Backflow/siphon | Anti-siphon hole/check valve/air gap |

Pump dosing should be calibrated in firmware as `ml_per_second`, measured during assembly.

### 7.4 Circulation fan — removed from V1

V1 has **no circulation fan**. It was removed from the mechanical and electrical design: the open
frame relies on passive convection, there is no forced airflow, and the only lever firmware has over
canopy temperature is derating/cutting the grow LED (see §5.3, §9.7). With no fan there is also no
active humidity control — the climate logic only warns.

This heading is retained as a placeholder so the rest of §7's numbering and cross-references stay
stable. A fan could be reconsidered for a future enclosed variant; if so, restore the quiet
80/92 mm PWM-fan-with-tach-and-guard requirements from spec v1.1.

### 7.5 Sensors

#### Required sensors

| Sensor | Recommended part class | Placement | Purpose |
|---|---|---|---|
| Air temp/humidity | SHT31/SHT35/SHT40/SHT41-class digital sensor | Mid-height, shaded from LED, near canopy | Climate/VPD |
| Soil/substrate moisture | Capacitive probe, corrosion-resistant | Root zone, removable | Watering decision |
| Reservoir level | Float switch + optional analog/pressure/optical | Reservoir | Low-water safety |
| Leak sensor | Conductive trace or sensor strip | Bottom tray below reservoir/pump | Pump lockout |
| Pump current | Current sense resistor/INA219-class | Pump rail | Pump fault/clog/dry-run detection — **required** in V1 (watering reliability is the core function; see §23 DR-04) |

#### Optional sensors

| Sensor | V1 status | Reason |
|---|---|---|
| Light/PAR sensor | Optional dev tool | Useful for calibration, not required for every unit |
| Pot weight/load cell | Optional expansion | Strong water-use signal but mechanical complexity |
| pH sensor | Not V1 | Calibration/maintenance burden |
| EC sensor | Not V1 | Calibration/maintenance burden |
| Camera | Not V1 | Scope creep |
| CO₂ | Not V1 | Indoor tabletop product cannot control CO₂ meaningfully |

### 7.6 Soil moisture sensor details

Use a **capacitive** moisture sensor, not a resistive probe, to reduce corrosion.

Requirements:

- Must be conformal-coated except sensing area if needed.
- Must use a replaceable connector.
- Cable must be strain-relieved.
- Firmware must support calibration.
- Default thresholds must be validated against chosen potting mix.
- Sensor must fail safe: implausible reading disables auto-watering and shows fault.

Recommended calibration model:

```text
raw_air
raw_dry_media
raw_field_capacity_media
raw_saturated_media

normalized_moisture = map(raw, dry_media, saturated_media, 0..100)
```

Do not assume one sensor’s raw ADC values apply to all media and all probes.

### 7.7 Reservoir

Target:

| Parameter | Target |
|---|---:|
| Volume | 4–6 L |
| Removal | Tool-free |
| Fill method | Pull-out reservoir or front/top fill |
| Cleaning | Hand-cleanable opening |
| Material | Food-safe plastic preferred |
| Level sensing | Low-level required; full/percent optional |
| Spill handling | Overflow path to leak tray, not electronics |
| Pump access | Tool-free filter cleaning |

Reservoir should be below the pot and electronics. If a fill opening is near electronics, add physical barriers and guttering to route spills away.

### 7.8 Power architecture

Use external certified AC/DC power brick.

Recommended:

```text
AC mains
→ certified external 24 VDC power brick
→ grow unit low-voltage DC only
```

Power budget:

| Load | Typical | Peak |
|---|---:|---:|
| LED | 50–100 W | 100 W |
| Pump | 3–10 W | 15 W |
| MCU/sensors/status | <2 W | 5 W |
| Headroom | 20% | 25% |

Recommended PSU:

- 24 VDC, 120 W for 60–80 W LED builds.
- 24 VDC, 150 W for 100 W LED builds.
- Certified CE/UL-equivalent external brick.
- Barrel jack or locking DC connector rated for current.
- Input fuse inside unit.
- Reverse-polarity protection.
- TVS diode.
- Power switch optional.

Rails:

```text
24 V: LED driver, optional 24 V pump
12 V: optional 12 V pump only (rail can be omitted if a 5 V pump is used — no fan in V1)
5 V: sensors/peripherals
3.3 V: MCU
```

### 7.9 PCB requirements

| Area | Requirement |
|---|---|
| Layers | 2-layer acceptable; 4-layer preferred for cleaner power/ground |
| Connectors | Locking JST/Molex/Wago-style; no loose Dupont for production build |
| Test points | Every rail, I2C, UART, pump drive, LED dimming, sensor inputs |
| Protection | Fuse, reverse polarity, TVS, flyback where needed, current limits |
| Wet isolation | PCB in dry bay only; conformal coat optional but not substitute for enclosure |
| Mounting | Standoffs, no board flex, serviceable |
| Silkscreen | Connector names, polarity, voltage, warning marks |
| Debug | USB-C or UART header |
| Boot/reset | Accessible during assembly, hidden in normal use |
| Expansion | Camera/light/pH/EC headers optional but unpopulated |

### 7.10 PCB trace/current constraints

Minimum engineering requirements:

- Use trace-width calculator in CI or documented DRC notes for pump/LED current paths.
- Do not route high-current LED power through thin control traces.
- Keep LED current loop away from sensor ADC lines.
- Separate analog moisture sensor area from high-current switching.
- Star or partition grounds if analog readings are noisy.
- Use screw/lever terminals or locking connectors for >1 A loads.
- Thermal relief should not compromise current-carrying paths.
- Add copper pours for MOSFET heat dissipation.
- MOSFETs must be logic-level at 3.3 V gate drive or use driver.

### 7.11 Status LED board

Use a separate small front-panel PCB.

Requirements:

- 5 indicator positions.
- RGB or separate colored LEDs acceptable.
- Diffuser strip.
- Current-limited.
- PWM dimming for night mode.
- Patterns available:
  - steady
  - slow pulse
  - fast blink
  - double blink
  - off
- Colorblind support via position and pattern.

---

## 8. Mechanical Specification

### 8.1 Layout

Preferred V1 layout is an **open-frame vertical stack**:

```text
[Top/upper rear dry bay]
  PCB, LED driver, status wiring, power distribution

[Upper open grow area]
  LED fixture overhead, shielded from direct water path

[Middle open grow area]
  plant, support, air sensor

[Lower grow area]
  compact 8–10 L removable pot and drip/watering outlet

[Bottom wet bay]
  removable 2.5–4 L reservoir, pump, filter, leak tray
```

Do not use a sealed box as the default. The frame should be visually open, with only enough structure to hold the light, cable channel, reservoir, electronics bay, and optional trellis.

### 8.2 Mechanical modules

| Module | Files | Notes |
|---|---|---|
| Frame | STEP + printable brackets | Wood/aluminum/printed hybrid |
| Light mount | STEP + STL | Adjustable height preferred |
| Pot tray | STEP + STL | Captures overflow |
| Reservoir bay | STEP + STL | Tool-free removal |
| Electronics bay | STEP + STL | Dry, serviceable |
| Cable channel | STEP + STL | Separate water tube and wiring |
| Status LED diffuser | STEP + STL | Clean front UI |
| Sensor clips | STL | Replaceable |
| Trellis/support | STL/STEP | Optional support ring/stake mount |

### 8.3 Materials

Recommended:

| Part | Material |
|---|---|
| Wet bay/reservoir-adjacent printed parts | PETG, ASA, ABS |
| LED-adjacent parts | ASA, ABS, aluminum, or heat-proven PETG |
| Decorative trim | Wood, bamboo, veneer, printed wood-fill only if away from moisture/heat |
| Transparent/diffuser | Frosted acrylic, PETG, polycarbonate |
| Gaskets | Silicone |
| Fasteners | Stainless steel where near water |
| Tubing | Silicone or PVC |
| Pot | Food-safe plastic, ceramic, or coated planter insert |

Avoid:

- PLA near LED heat or persistent humidity.
- Exposed MDF in wet areas.
- Untreated wood in splash zones.
- Hidden screws under reservoir water path.

### 8.4 Serviceability

The user must be able to:

- Remove reservoir without moving the plant.
- Remove pump/filter for cleaning.
- Remove pot without cutting wires.
- Replace moisture probe.
- Replace LED fixture.
- Access electronics without opening wet bay.
- Inspect tubing.
- Clean leak tray.

### 8.5 Cable and tube routing

Rules:

- Wires and tubes must be separated where possible.
- Use drip loops before entering electronics bay.
- No cable enters electronics bay from directly below without a drip loop and grommet.
- Tubing should be visible or inspectable enough to find leaks.
- Add strain relief at all moving/removable modules.
- Use labels for pump, LED, moisture, reservoir, leak.

### 8.6 Light/plant clearance

- LED height must allow 150–300 mm clearance above typical canopy.
- If fixed-height, design total grow zone height ≥600 mm.
- Plant support should keep branches away from the LED.
- Include pruning guidance because Carolina Reaper can outgrow the tabletop unit.

### 8.7 Acoustic design

Noise target. With no fan in V1, the device is effectively silent except during short pump pulses,
so the pump is the only meaningful noise source:

| Mode | Target |
|---|---:|
| Normal day mode | ≤30 dBA at 1 m (near-silent — no fan) |
| Night mode | ≤25 dBA at 1 m |
| Pump active | ≤35 dBA at 1 m, short duration |

Mechanical noise mitigations:

- Rubber pump pad/suction cups.
- Avoid hard tubing vibrating against frame.
- Use soft-start pump if possible.
- Avoid resonant thin panels.

---

## 9. Firmware Specification

### 9.1 Firmware goals

- Fully local operation.
- Deterministic rules.
- No internet dependency.
- Safe defaults.
- Fault-first design.
- Testable control logic independent of hardware.
- Optional telemetry, not required.

### 9.2 Firmware language and architecture

**Language: Rust** (`no_std`), using the `esp-hal` bare-metal ecosystem for the ESP32-S3. Rust is
chosen for this safety- and fault-first controller (§9.1): ownership/borrow checking removes whole
classes of memory bugs, and the type system lets the state machine (§9.3) and fault priorities be
encoded as compiler-checked state types rather than runtime conventions. The core control logic lives
in a platform-agnostic `no_std` crate that compiles and unit-tests on the host with stable Rust, so no
hardware is needed to validate rules (§10.1).

Toolchain note: the ESP32-S3 is Xtensa, which is not on upstream stable Rust; install the Espressif
Rust channel with `espup` and pin it via `rust-toolchain.toml`. Flashing/monitoring uses `espflash`.
Host-only crates build with ordinary stable Rust. (Telemetry, §9.11, uses `esp-wifi` behind a Cargo
feature and is never required for control.)

Recommended structure (a Cargo workspace):

```text
firmware/
  Cargo.toml              # workspace manifest
  rust-toolchain.toml     # pins the esp Rust channel (espup)
  .cargo/config.toml      # default target xtensa-esp32s3-none-elf + espflash runner
  control/                # no_std, platform-agnostic control logic — host-testable
    src/
      lib.rs
      app_state.rs
      plant_profile.rs
      scheduler.rs
      irrigation_controller.rs
      light_controller.rs
      climate_controller.rs
      safety_controller.rs
      led_status.rs
      hal.rs              # sensor/actuator/clock traits (the hardware seam)
    tests/                # host unit + integration tests
  controller/             # no_std esp-hal binary for ESP32-S3 — binds traits to real peripherals
    src/
      main.rs
      sensors/
      actuators/
      drivers/
  sim/                    # host scenario runner driving the control crate (no hardware)
    src/
    scenarios/
    models/
  hil/
    fixtures/
  tools/
```

Dependency rule: `control/` depends only on its own `hal.rs` traits, never on `esp-hal`. `controller/`
and `sim/` provide concrete trait implementations (real peripherals vs. simulated models).

### 9.3 Firmware state machine

Required states:

```text
BOOT
SELF_TEST
NORMAL
WATERING
LOW_WATER
LEAK_DETECTED
SENSOR_FAULT
PUMP_FAULT
LED_FAULT
OVER_TEMP
MAINTENANCE
SAFE_SHUTDOWN
```

(`FAN_FAULT` was removed in V1 — there is no fan.)

State priority:

```text
LEAK_DETECTED
> OVER_TEMP critical
> PUMP_FAULT
> SENSOR_FAULT affecting watering
> LOW_WATER
> NORMAL/WATERING
```

### 9.4 Boot behavior

On boot:

1. Initialize hardware.
2. Run self-test.
3. Read persistent config/calibration.
4. Validate sensor ranges.
5. Restore grow-cycle age from RTC/NVS.
6. Determine light schedule state.
7. Ensure pump is off.
8. Set LEDs.

If RTC time is invalid:

- Use monotonic fallback schedule from boot.
- Light schedule defaults to conservative 16h on / 8h off.
- System LED amber pulse.
- Do not block watering if moisture sensing is valid.

### 9.5 Light control

#### Default schedule

| Stage | Photoperiod | Ramp | Intensity target |
|---|---:|---:|---:|
| Germination pre-emergence | 0–8 h optional | none | off/low |
| Germination after emergence | 16 h | 30 min | 20–30% |
| Seedling | 16 h | 30 min | PPFD 140–210 |
| Vegetative | 16 h | 30 min | PPFD 245–350 |
| Flowering | 16 h | 30 min | PPFD 315–420 |
| Fruiting | 16 h | 30 min | PPFD 350–435 |

Light starts at a default time if RTC known:

```text
Lights on: 06:00 local
Lights off: 22:00 local
```

If no RTC/time setup:

```text
First boot time = start of light period
16h on / 8h off thereafter
```

#### Thermal derating

If air temperature is high:

| Condition | LED action |
|---|---|
| 28–30°C | No derate (monitor only — no fan in V1) |
| 30–32°C | Reduce LED up to 20% if temperature rising |
| >32°C | Reduce LED 30–60%; climate fault |
| >35°C | LED off/minimum; critical fault |

If LED heat sink sensor is added:

| LED temp | Action |
|---|---|
| <60°C | Normal |
| 60–70°C | Dim slightly |
| >70°C | Derate |
| >80°C | LED off fault |

### 9.6 Irrigation control

#### Inputs

- Normalized moisture.
- Moisture sensor validity.
- Reservoir low/not low.
- Leak detected/not detected.
- Pump calibration ml/s.
- Current stage.
- VPD.
- Time in photoperiod.
- Recent watering history.
- Pump current optional.

#### Decision loop

Run every 5 minutes for checks, but water only when conditions require.

Pseudo-code:

```pseudo
if leak_detected:
    pump.off()
    state = LEAK_DETECTED
    return

if reservoir_low:
    pump.off()
    state = LOW_WATER
    return

if moisture_sensor_invalid:
    pump.off()
    state = SENSOR_FAULT
    return

if pump_fault:
    pump.off()
    return

stage = plant_profile.stage(age_days)
thresholds = irrigation_thresholds(stage, vpd, time_of_day)

if moisture < thresholds.critical_dry:
    dose = thresholds.emergency_pulse_ml
    water_even_if_night = true
elif moisture < thresholds.dry and within_watering_window():
    dose = thresholds.normal_pulse_ml
else:
    pump.off()
    return

if daily_watered_ml + dose > daily_max_ml(stage):
    state = PUMP_FAULT_OR_WATERING_LIMIT
    pump.off()
    return

run_pump_for(dose / calibrated_ml_per_second)
wait(recheck_delay)
remeasure moisture

if moisture did not increase by minimum_expected_delta after N pulses:
    state = PUMP_FAULT
```

#### Daily maximums

Initial defaults:

| Stage | Daily max |
|---|---:|
| Seedling | 250 mL/day |
| Vegetative | 800 mL/day |
| Flowering | 1200 mL/day |
| Fruiting | 1800 mL/day |

These are safety caps, not target consumption. They should be adjusted after grow trials.

#### Pump timeout

- Absolute single-run max: 30 seconds, or lower depending on calibrated flow.
- Maximum pulses per hour: 3.
- Maximum pulses per day: stage-dependent.
- Pump always off on firmware crash/reset due to hardware pull-down.

### 9.7 Climate monitor

V1 has **no fan**, so the climate controller commands no actuator. It computes VPD, classifies the
air for the Climate status LED, and — past 32 °C — requests an LED derate (the only way to shed heat
without a fan). It never tries to cool below ambient.

Climate classification (drives the Climate LED, §9.8):

| Condition | Climate LED | Other action |
|---|---|---|
| RH >85% | amber | disease-risk warning |
| RH >90% sustained | red | disease-risk warning; prompt the user to ventilate the room |
| VPD <0.4 kPa (too humid) | amber | avoid watering unless dry |
| VPD >1.6 kPa (stress) | amber | alert if persistent |
| Temp >30 °C | amber | prevent additional LED heat if rising |
| Temp >32 °C | red | request LED derate (only heat lever) |
| Temp <16 °C | amber | do not increase watering |
| RH/temp outside the stage's preferred band | amber | — |

Over-temp protection rests entirely on the LED: at the >35 °C critical threshold the safety machine
enters OVER_TEMP and forces the LED off/minimum (§9.3, §9.5).

### 9.8 LED status logic

| LED | Green | Amber | Red |
|---|---|---|---|
| Water | Reservoir OK | Low soon / level uncertain | Empty / low lockout |
| Moisture | In target | Dry soon / wet high | Sensor fault / critical dry / waterlogged |
| Light | Schedule active/normal | Thermal dimming / schedule uncertain | LED fault / over-temp shutdown |
| Climate | Temp/VPD OK | Outside preferred range | Critical temp/humidity fault |
| System | Normal heartbeat | Maintenance/calibration due | Self-test/fatal fault |

Blink patterns:

| Pattern | Meaning |
|---|---|
| Steady | OK |
| Slow pulse | Warning |
| Fast blink | User action needed |
| Double blink | Sensor fault |
| Off at night | Normal only if system LED heartbeat remains dim |

### 9.9 Calibration

V1 must separate hidden/developer calibration from user configuration.

Required calibrations:

| Calibration | Method |
|---|---|
| Moisture dry/wet | Factory/dev mode with chosen media |
| Pump ml/s | Run pump into measuring cylinder for 30 s |
| Reservoir low point | Fill-drain test |
| LED dim map | Measure PPFD grid at 25/50/75/100% |
| Temp/humidity sanity | Compare against reference sensor |
| Leak sensor | Wet test |

Calibration data stored in NVS/flash:

```json
{
  "moisture_raw_dry": 1234,
  "moisture_raw_wet": 2870,
  "pump_ml_per_sec": 3.8,
  "led_ppfd_map": {
    "25": 120,
    "50": 240,
    "75": 360,
    "100": 480
  },
  "reservoir_low_adc": 600
}
```

### 9.10 Data logging

Store rolling logs locally:

- Sensor readings every 5–15 minutes.
- Watering events.
- Fault events.
- LED derating events.
- Reservoir-low events.
- Firmware version.
- Calibration version.

Minimum persistent log size:

- 7 days onboard.
- Export via serial/USB.
- Optional Wi-Fi telemetry.

### 9.11 Connectivity

V1 must work offline.

Optional connectivity modes:

| Mode | Status |
|---|---|
| USB serial logs | Required for dev |
| Local Wi-Fi setup | Optional |
| MQTT | Optional |
| Home Assistant discovery | Optional |
| Matter | Future |
| Cloud | Not V1 |

No control loop may depend on cloud.

---

## 10. Software Testing and Simulation

### 10.1 Testing philosophy

Every control rule should be testable without physical hardware.

Design firmware so the core logic lives in the `no_std` `control` crate, which compiles for the host
with stable Rust and is tested with `cargo test` (no target hardware, no Xtensa toolchain needed):

```text
hardware drivers        → trait mocks (host impls of the hal.rs traits)
sensor readings         → simulated
time                    → simulated (injected Clock trait)
control decisions       → asserted
```

### 10.2 Unit tests

Required unit tests:

| Module | Tests |
|---|---|
| DLI calculator | PPFD/DLI conversion correctness |
| Plant profile | Stage selection by age |
| Light scheduler | On/off/ramp behavior |
| LED derating | Derate thresholds |
| Moisture normalization | Raw-to-normalized mapping |
| Irrigation thresholds | Stage/VPD/time modifiers |
| Pump dose calculator | ml to seconds conversion |
| Pump safety | timeout, daily max, low water, leak lockout |
| VPD calculator | temp/RH to kPa |
| Climate monitor | temp/RH/VPD health classification + LED-derate request (no fan in V1) |
| LED status | state-to-pattern mapping |
| Fault priority | highest-priority state wins |
| Calibration store (flash) | defaults, missing/corrupt calibration |

### 10.3 Simulation tests

Create a simple plant/environment simulator sufficient for control validation.

Simulated variables:

```text
air_temp_c
relative_humidity
vpd_kpa
moisture_normalized
reservoir_ml
light_on
led_power_percent
pump_ml_per_sec
plant_stage
```

Simulated behaviors:

- Moisture declines faster during light period and high VPD.
- Pump increases moisture after delay.
- Reservoir decreases when pump runs.
- LED increases heat (no fan to disperse it — air RH tracks the room).
- Leak sensor can be injected.
- Sensor failure can be injected.

Required scenarios:

| Scenario | Expected result |
|---|---|
| Normal 7-day seedling | No overwatering, light schedule stable |
| Normal 7-day fruiting | Moisture maintained, reservoir consumed |
| Reservoir empty | Pump lockout, water LED red |
| Moisture sensor stuck wet | No watering, sensor fault after plausibility window |
| Moisture sensor stuck dry | Pump capped by daily max, fault if no response |
| Pump disconnected | Current/timing fault if current sensor present; moisture no-rise fault otherwise |
| Leak detected | Immediate pump off, red water/system |
| Hot room | LED derate (only heat lever — no fan), climate red, no runaway |
| Humid night | Climate flags red (no fan to act), no watering unless critical dry |
| RTC invalid | Safe schedule fallback, amber system |
| Power loss mid-watering | Pump off after reboot, event logged |

### 10.4 Hardware-in-loop tests

Build a HIL test fixture with:

- Programmable moisture input or digital mock.
- Reservoir switch simulator.
- Leak switch simulator.
- Pump dummy load.
- LED dimming dummy input.
- Current measurement.
- UART log capture.

HIL tests:

- Flash firmware.
- Verify boot self-test.
- Toggle each sensor state.
- Confirm pump output never enables during leak/low-water.
- Confirm LED dimming command changes.
- Confirm status LED patterns.
- Confirm watchdog resets safely.

### 10.5 Continuous integration

Repo CI should run:

- Markdown lint.
- Firmware formatting (`cargo fmt --check`).
- Static analysis / lints (`cargo clippy -D warnings`).
- Host unit tests (`cargo test` on the `control` crate, stable Rust).
- Simulation tests (`sim` scenarios over the `control` crate).
- Schematic ERC if tool supports CLI.
- PCB DRC if tool supports CLI.
- BOM generation check.
- CAD file presence check.
- STL manifold check if feasible.
- Link/reference check for docs.

---

## 11. PCB and Electronics Verification

### 11.1 Design reviews

Before ordering PCB:

- Schematic review.
- Power budget review.
- Connector/pinout review.
- Protection review.
- Wet/dry isolation review.
- Firmware pin mapping review.
- PCB DRC/ERC pass.
- Trace current review.
- Thermal review for MOSFETs/regulators.
- Assembly review with mechanical CAD.

### 11.2 Bench bring-up plan

1. Visual inspection.
2. Continuity checks:
   - 24 V to GND no short.
   - 12 V to GND no short.
   - 5 V to GND no short.
   - 3.3 V to GND no short.
3. Power with current-limited bench supply.
4. Verify rails unloaded.
5. Verify regulator temperatures.
6. Flash test firmware.
7. Verify USB/UART.
8. Verify each sensor bus.
9. Verify each output with dummy load.
10. Verify pump MOSFET with real pump in water.
11. Verify LED dimming with driver.
12. Verify status LED board.
13. Run 24-hour dry burn-in without water.
14. Run 24-hour wet-bay test with water but no plant.

### 11.3 PCB trace tests

Required artifacts:

- Trace-width calculation for each power path.
- Maximum current table.
- Thermal camera image at max pump/LED-control load.
- Voltage-drop measurement under max load.
- MOSFET temperature measurement at 100% pump.
- Regulator temperature measurement at worst-case ambient.
- Connector current rating table.

### 11.4 Electrical safety verification

Even with low-voltage DC:

- External PSU must be certified.
- Add input fuse.
- Add reverse polarity protection.
- No AC mains inside the grow unit.
- Drip loops required.
- Electronics bay splash-protected.
- Pump output fails off on MCU reset.
- Watchdog enabled.
- Brownout detector enabled.
- Fault states persist until safe conditions return; leak fault requires manual clear.

---

## 12. Mechanical Verification

### 12.1 CAD verification

Before printing/building:

- Full assembly CAD complete.
- Pot inserted/removed path checked.
- Reservoir inserted/removed path checked.
- Pump/filter access checked.
- Cable bend radius checked.
- Tubing path checked.
- LED height/clearance checked.
- Electronics bay access checked.
- Tool access checked.
- Center of gravity checked with full reservoir and plant.
- Drip/leak path checked.

### 12.2 Printed part verification

Use tolerance coupons before printing large parts:

- Snap-fit test.
- Screw boss test.
- Heat-set insert test.
- Tube clip test.
- Diffuser slot test.
- Cable channel clip test.
- Reservoir rail/slide test.

Acceptance:

- No cracking.
- No excessive force required.
- No sharp edges near tubing.
- No loose light mounts.
- Parts survive 40°C warm environment without warping.

### 12.3 Water path verification

Tests:

| Test | Method | Acceptance |
|---|---|---|
| Reservoir fill | Fill to max | No splash into dry bay |
| Reservoir removal | Remove when full | No more than minor drip into wet tray |
| Pump run | 100 cycles | No leaks |
| Tube disconnect simulation | Controlled failure | Water goes to tray/leak sensor |
| Overflow | Overfill intentionally | Overflow path avoids electronics |
| Leak sensor | Add small water amount | Pump locked out |
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

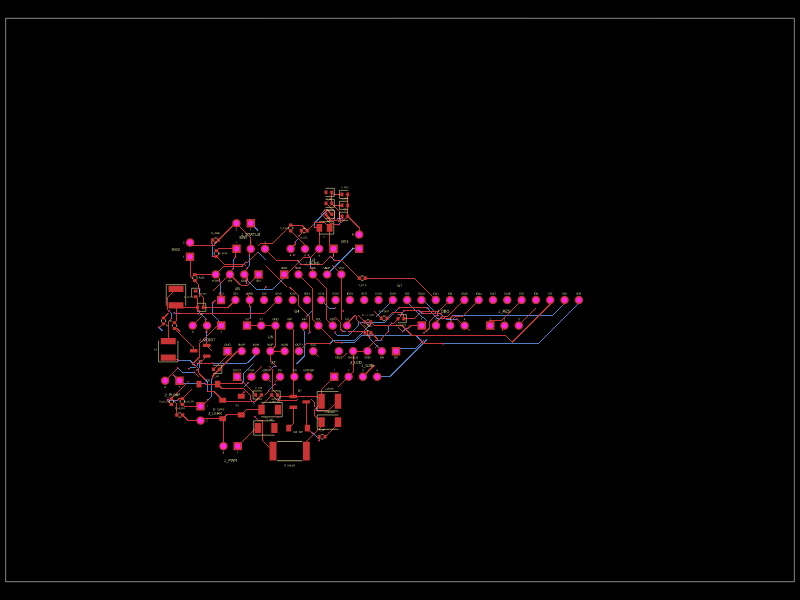
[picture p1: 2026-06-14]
electronics/pcb/programmatic/out/controller.pcb.png

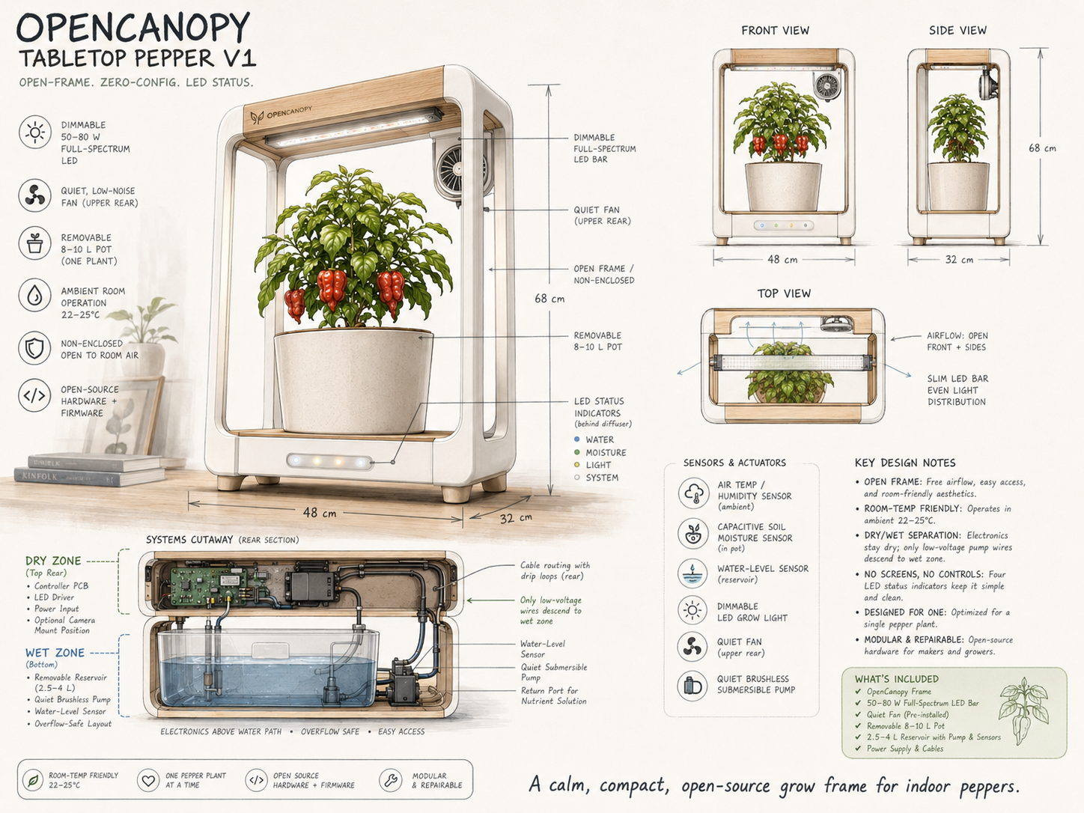
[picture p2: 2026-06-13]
mechanical/reference/opencanopy-sketch-v1.png

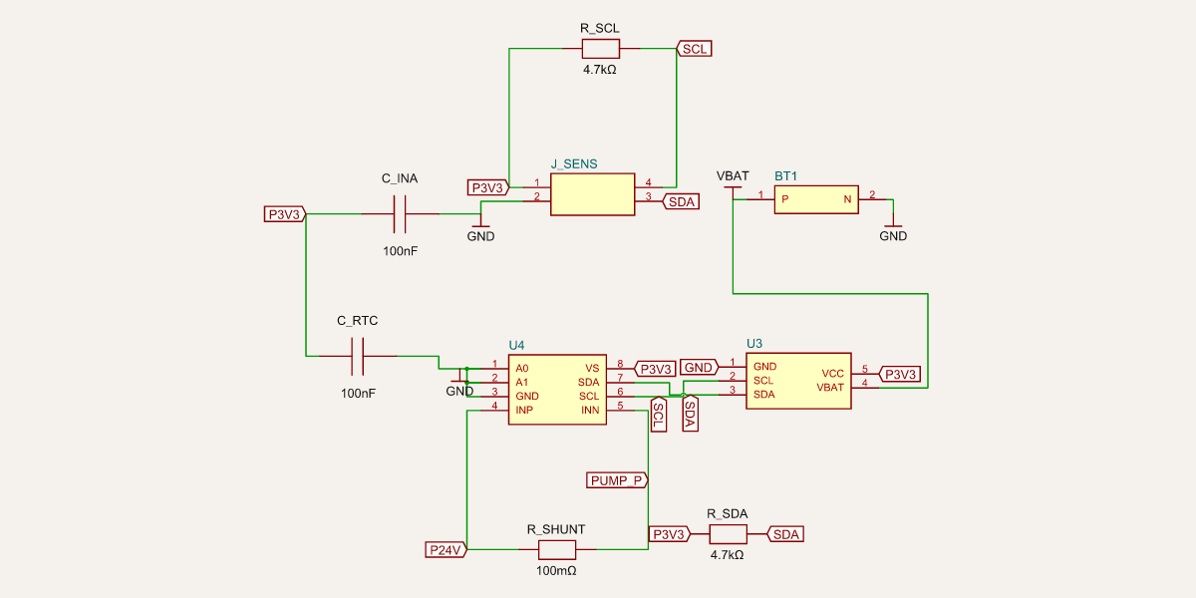
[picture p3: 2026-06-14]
docs/assets/renders/e-sch-i2c-rtc-current.png

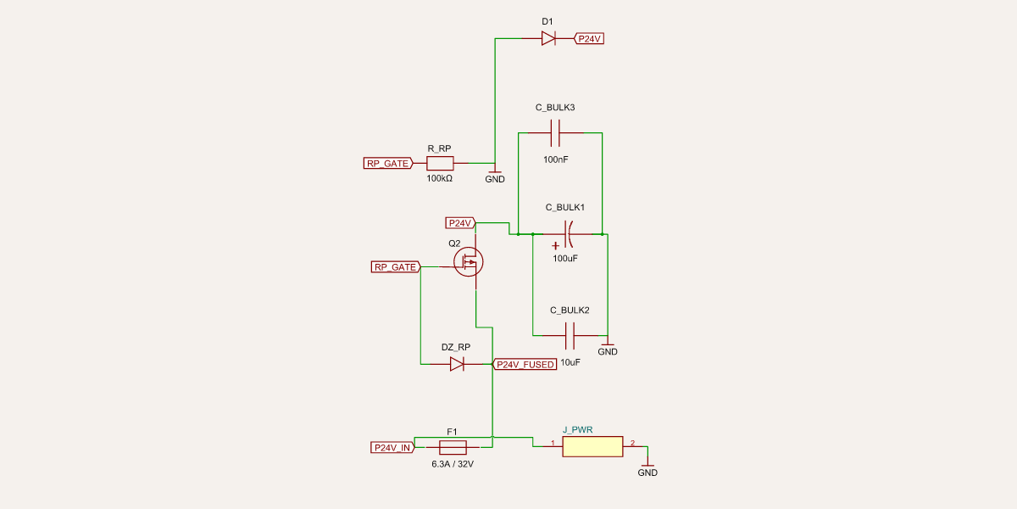
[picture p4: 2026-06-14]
docs/assets/renders/e-sch-power-input.png

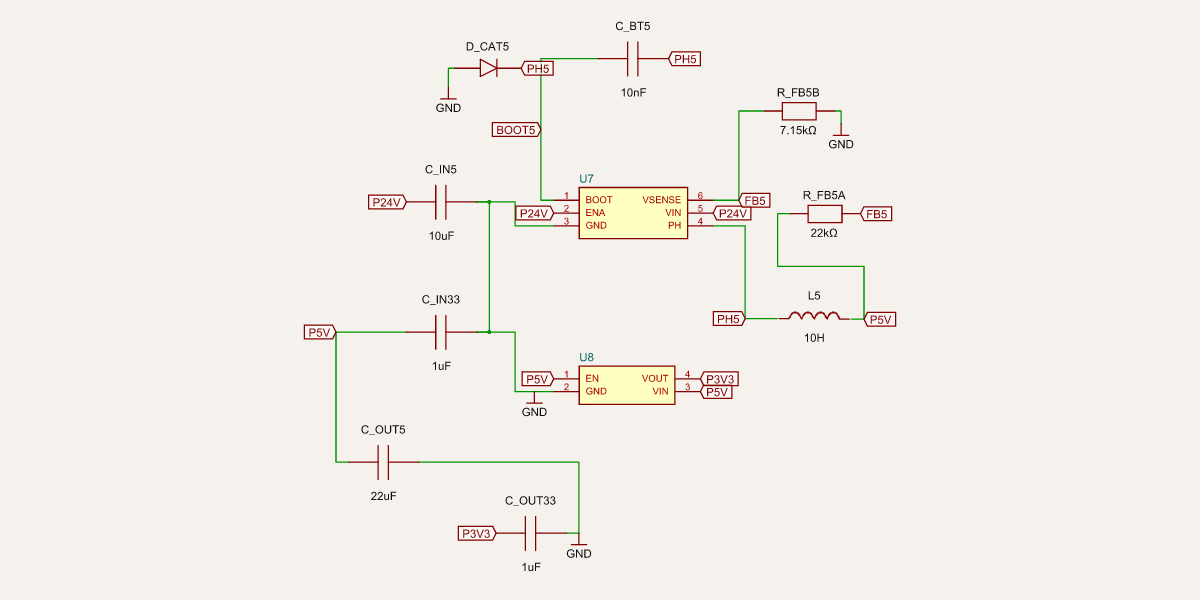
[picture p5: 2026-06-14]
docs/assets/renders/e-sch-power-rails.png

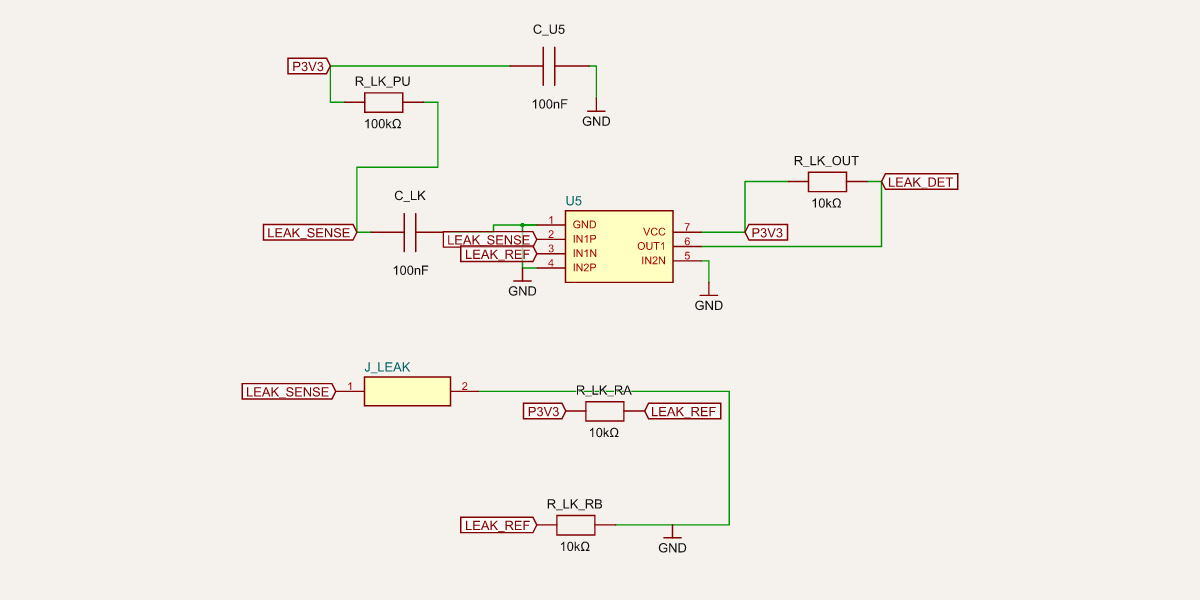
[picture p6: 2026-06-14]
docs/assets/renders/e-sch-leak-detect.png

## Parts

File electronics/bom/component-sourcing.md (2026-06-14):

<!-- SPDX-License-Identifier: CC-BY-4.0 -->
# Component sourcing — pump, grow light, status LEDs, cables

**Owner:** Electronics (component selection + BOM is this track's), coordinating **firmware** (driver
interfaces) and **mechanical** (3D models for the enclosure). **Date:** 2026-06-14.
**Spec refs:** §7.2 (light), §7.3 (pump), §7.11 (status LEDs), §16.1/§16.3 (BOM), §17.1 (no mains inside).

This picks **real, orderable parts** for the four field components the maintainer flagged, against the
interfaces firmware already expects, and lists where mechanical can get a **3D/STEP model** for each.
It also surfaces two integration findings that need firmware + a project decision (§6).

## 0. What firmware already expects (the constraints we source to)

| Component | Firmware/electronics interface (already built) |
|---|---|
| Pump | 2-wire **24 V DC**, low-side N-FET switched (`Q1`, GPIO10), INA219 current sense across `R_SHUNT`, `D2` flyback. On/off today; PWM-capable. Calibrated `pump_ml_per_sec`. |
| Grow light | **PWM-dimmable** driver (GPIO14), `led_ppfd_25/50/75/100` calibration map, PPF ~150 µmol/s / PPE ≥2.5, full-spectrum + 660 nm, **driver DC-fed from the 24 V rail** (no mains inside — §17.1/S1). |
| Status LEDs | 5× **WS2812B addressable** RGB, single-wire (GPIO21/RMT), 5 V (4.5 V via series diode). `led_status` renders colour+pattern. |
| Cables | The chosen locking/keyed connectors ([connector-spec.md](../wiring/connector-spec.md)) + wire gauges from the [harness table](../wiring/harness-table.csv). |

## 1. Status LEDs — **settled**

**Worldsemi WS2812B-2020** (2.0 × 2.0 mm addressable RGB). 5 on the front-panel board (PCB2).

- **Buy:** LCSC **C965555** (JLCPCB-stocked for assembly). [LCSC](https://www.lcsc.com/product-detail/C965555.html) · [JLCPCB](https://jlcpcb.com/partdetail/Worldsemi-WS2812B2020/C965555)
- **Operating range 3.7–5.3 V** — this **validates our 5 V→4.5 V series-diode design** (`D_LVD`): at 4.5 V the data V_IH ≈ 0.7·VDD = 3.15 V, so the 3.3 V data line has margin.
- **3D model — checked in:** [`../pcb/3d-models/WS2812B-2020_C965555.step`](../pcb/3d-models/WS2812B-2020_C965555.step) (+ `.wrl`), a real BREP solid pulled from LCSC/EasyEDA. *Mechanical also needs the PCB2 outline, not just the individual LED model.*
- **Alternate:** discrete RGB + TLC59116 I²C driver (already in `alternates.csv`).

## 2. Pump — TOPSFLO TL-B series (brushless DC, submersible)

**TOPSFLO TL-B03H** (24 V brushless DC micro centrifugal, **IP68 submersible**, seal-less, food-grade,
>20 000 h, continuous-rated). Family page: [topsflo.com](https://www.topsflo.com/brushless-dc-pump/24v-dc-water-pump-tl-b03h.html) · [TL-B10 datasheet PDF](https://pdf.directindustry.com/pdf/topsflo-industry-technology-co-limited/tl-b10-12v-24v-brushless-dc-water-pump/160944-733491.html)

- **Specs (TL-B03H):** 24 V, max lift **2.5 m**, max flow **6.5 L/min (390 L/h)**, food-grade, IP68.
  At our operating point (~1 m head, 80–240 L/h) it runs well **under 5 W** — matches §7.3.
- **Firmware fit:** plain 2-wire 24 V DC motor → low-side FET switch (`Q1`) + `D2` flyback + INA219
  current sense exactly as built. Brushless = quiet + continuous-rated (vs a brushed pump). ✔
- **Pick the exact model** (TL-B03H / TL-B04 / TL-B10) off the head–flow curve once the reservoir
  height + tubing run are fixed by mechanical; all share the same 2-wire interface.
- **3D / datasheet:** TOPSFLO provides datasheets (directindustry) and **CAD/STEP on request**
  (`info@topsflo.com`) — request the STEP for the chosen model for mechanical.
- **Alternate:** a generic 24 V brushless DC submersible (cheaper, but no datasheet/3D — fails the
  "real data" bar we hold the light to; acceptable for the pump as a fallback only).

## 3. Grow light — LED engine + **DC-DC dimmable driver** (the cross-domain crux)

This is the one part where a single off-the-shelf fixture does **not** drop in, because **§17.1
forbids mains inside the unit** (risk **S1**, Critical). Every consumer grow bar (Spider Farmer, ECO
Farm, Yearld, etc.) is a **mains-input** fixture — they can't go in the dry bay. So the driver inside
the unit must be **DC-DC, fed from the 24 V rail**.

### 3.1 LED engine

**Samsung LM301H / LM301H EVO** (or LM301B) horticulture board, 3000–3500 K white + **660 nm** deep
red (Osram/Epistar), ~60 W, **PPE 2.7–3.1 µmol/J**. The Samsung diode has a full
[datasheet](https://download.led.samsung.com/led/file/resource/2022/05/Data_Sheet_LM301H_CRI80_Rev.5.4.pdf)
(SPD, PPE) — the real spectral/efficacy data §16.3 requires. **Panel form** (distributed emitters) for
the ≥0.6 uniformity at 150 mm that PL-06 needs. Bare boards: Kingbrite / Bavagreen / ECO Farm
(specify a ~60 W board; finalise the SKU against a published PPFD map for DR-01/PL-06).

### 3.2 Driver — Mean Well **LDD-1000H** (×N), DC-DC constant-current, **logic-level PWM**

[LDD-H series](https://www.ledsupply.com/led-drivers/mean-well-ldd-h-series-cc-step-down-mode) · [Mean Well](https://www.meanwell-web.com/en/ldd-series)

- **Input 9–56 VDC** → fed from our **24 V rail** (no mains, S1-compliant). ✔
- **PWM dim is logic-level:** DIM "ON" = **2.5–6 VDC**, frequency **100 Hz–1 kHz**. Our **3.3 V MCU PWM
  drives it directly — no op-amp, no level shifter.** ✔✔ (This lets us **delete the 0-10 V op-amp path**
  `U9` — see §6.)
- **Step-down** (output < input): from 24 V the usable string is ≤ ~21 V, so ~**21 W per LDD-1000H** →
  budget **~3× LDD-1000H for 60 W**, with the LED board split into ≤21 V strings. Final count is set
  during the LED-board electrical layout (board Vf/current).
- **3D / datasheet:** Mean Well publishes the LDD-H datasheet + **STEP model**; 31.8 × 20.3 × 12.2 mm.

### 3.3 The simpler alternative (needs a project decision)

A single **Mean Well HLG-60H-C AB** (70 W constant-current, **3-in-1 dim: 0-10 V / PWM / resistance**,
IP65/67, [STEP model](https://www.meanwell.com/Upload/PDF/HLG-60H-C/HLG-60H-C-SPEC.PDF)) is **one part**
and a much cleaner driver — **but it is AC-mains input**, so it can only live **outside** the unit
(like the 24 V PSU). That keeps mains external (still S1-compliant) but **moves the driver out of the
dry bay** and means a second external brick + the dim signal entering the unit.

| Option | Driver | Mains? | Firmware fit | Complexity |
|---|---|---|---|---|
| **A (recommended)** | N× LDD-1000H from 24 V rail | none inside | **best** — 3.3 V PWM direct | 3 modules + board split |
| B | 1× external HLG-60H-C AB | mains, **external only** | needs 10 V dim level-shift | 1 module, architecture change |

**Recommendation:** Option A (LDD-H) keeps the committed "DC driver in dry bay" architecture and is the
best firmware fit. Option B is simpler hardware but reopens the driver-placement decision — flag to the
**Project & Repo** track (§6).

## 4. Cables

The connectors are already chosen ([connector-spec.md](../wiring/connector-spec.md), with mfr part
numbers in [bom.csv](bom.csv)). What's left is the **wire**:

- **Silicone-insulated stranded** hook-up wire (flexible, heat/oil-resistant, good in the wet zone):
  **18 AWG** for 24 V power (`J_PWR`/`J_LED`), **20 AWG** pump (`J_PUMP`), **26–28 AWG** for signal/sensor
  runs. E.g. BNTECHGO / generic silicone wire (UL1007/UL3239-class).
- **Pre-crimped or self-crimped** to the JST VH/PH/XH + XT30 housings already specified; wet-zone runs
  get **drip loops + strain relief** per the connector spec.
- **3D:** the connector STEP models (JST, Amass XT30) carry the geometry mechanical needs; bulk wire is
  modelled as a routed path in the cable conduit (WI-ME-07).

## 5. 3D models for mechanical (where to get each STEP)

| Item | 3D / STEP source |
|---|---|
| Pump (TOPSFLO TL-B0x) | TOPSFLO (datasheet + STEP on request, `info@topsflo.com`) |
| LED board (LM301H) | flat board — model from the vendor's board dimensions; pair with the heatsink (WI-ME-05) |
| LED driver (LDD-1000H) | Mean Well STEP download (also HLG-60H STEP if Option B) |
| Status LEDs (WS2812B-2020) | **checked in:** [`pcb/3d-models/`](../pcb/3d-models/) (STEP+WRL, LCSC C965555); mechanical uses the **PCB2 outline** from WI-EE-09 for placement |
| Connectors (JST VH/PH/XH, XT30) | JST / Amass STEP via the manufacturer or SnapEDA |
| Float / leak / moisture probe | supplier model (request with the chosen part) |

The **big geometry** items mechanical actually needs to design around are the **pump**, the **LED
board + heatsink**, and the **LED driver(s)** — prioritise those STEP files.

## 6. Action items this surfaces

- **Firmware — grow-LED PWM frequency.** `controller/src/hw.rs` drives the grow-LED PWM on a **25 kHz**
  LEDC timer (inherited from the now-deleted fan). The LDD-H (and most LED drivers) accept PWM dimming
  only at **100 Hz–1 kHz** → **move the grow-LED channel to ~1 kHz** (a separate LEDC timer). Logic is
  host-testable; no silicon needed. *Until then dimming won't work with a real driver.*
- **Electronics — drop the 0-10 V op-amp path.** With the LDD-H taking 3.3 V PWM directly, the optional
  `U9` (MCP6001) + RC are unnecessary (and MCP6001's 6 V max never could make 0-10 V anyway). They are
  already DNP; remove from the netlist/BOM in a follow-up.
- **Project & Repo — driver placement decision (Option A vs B, §3.3):** DC-DC LDD array in the dry bay
  vs. a single external mains HLG. Affects the spec's "remote driver in upper dry bay" wording and the
  enclosure. Electronics recommends **A**; this is a locked-requirement change to log in the risk register.
- **Plant Science / DR-01:** finalise the LED-board SKU against a **published PPFD map** so PL-06's
  uniformity + the DLI target are met by the actual part (not just the model candidate).

## Sources

- [Mean Well LDD-H (LEDSupply)](https://www.ledsupply.com/led-drivers/mean-well-ldd-h-series-cc-step-down-mode) · [Mean Well LDD series](https://www.meanwell-web.com/en/ldd-series)
- [Mean Well HLG-60H-C spec](https://www.meanwell.com/Upload/PDF/HLG-60H-C/HLG-60H-C-SPEC.PDF)
- [Samsung LM301H datasheet](https://download.led.samsung.com/led/file/resource/2022/05/Data_Sheet_LM301H_CRI80_Rev.5.4.pdf) · [Samsung LM301H EVO](https://led.samsung.com/lighting/mid-power-leds/3030-leds/lm301h-evo/)
- [TOPSFLO TL-B03H](https://www.topsflo.com/brushless-dc-pump/24v-dc-water-pump-tl-b03h.html) · [TL-B10 datasheet](https://pdf.directindustry.com/pdf/topsflo-industry-technology-co-limited/tl-b10-12v-24v-brushless-dc-water-pump/160944-733491.html)
- [WS2812B-2020 (LCSC C965555)](https://www.lcsc.com/product-detail/C965555.html) · [SnapEDA 3D](https://www.snapeda.com/parts/WS2812B-2020/Worldsemi/view-part/)

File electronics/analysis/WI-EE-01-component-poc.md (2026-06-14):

<!-- SPDX-License-Identifier: CC-BY-4.0 -->
# WI-EE-01 — Component selection & breadboard PoC

**Status:** Selection + bench protocol complete; **bench measurements pending hardware**.
**Spec refs:** §7.1–§7.7, §16, §23 (DR-01, DR-04).
**Feeds:** schematic [WI-EE-03](WI-EE-03-schematic.md), power budget [WI-EE-02](power-budget.md),
BOM [WI-EE-07] ([bom.csv](../bom/bom.csv)).

> **Two-part work item.** *Component selection* (the design decision — concrete candidate parts that
> satisfy §7 and §16) is delivered here and is what the schematic/BOM/power-budget consume. The
> *bench logs* (M2-02…M2-08 measured data) require physical hardware on a breadboard; this document
> provides the **bench protocol, acceptance thresholds, and logging templates** so the PoC can be
> run and recorded the moment parts arrive. Measurement-dependent boxes are flagged below.

## 1. Selected components (candidate parts)

Each row is a concrete, orderable candidate that meets the §7 requirement and carries the data the
BOM (§16) needs. Alternates live in [alternates.csv](../bom/alternates.csv).

| # | Function | Candidate part | Key spec | Why / spec ref |
|---|---|---|---|---|
| 1 | **MCU** | ESP32-S3-DevKitC-1 (N8R8) | Xtensa LX7 dual, 8 MB flash / 8 MB PSRAM, Wi-Fi/BLE, ≥30 GPIO | §7.1 preferred; Rust `esp-hal`; camera-expansion headroom. **M2-01 ✔** |
| 2 | **Temp/RH** | Sensirion SHT40 (or SHT31-DIS-B) | I²C, ±0.2 °C / ±1.8 %RH, 0x44 | §7.5/§16.1 SHT3x/4x-class; mid-height shaded mount |
| 3 | **Soil moisture** | Capacitive v2 probe, conformal-coated, JST | Analog 0–3 V, corrosion-resistant | §7.6 capacitive only; replaceable connector, strain-relieved |
| 4 | **Reservoir low-level** | Vertical float switch (PP, reed) + optional eTape analog | Dry/closed contact; low-level reliable | §7.7 low-level required; full/percent optional |
| 5 | **Leak sensor** | Conductive trace pad / rope sensor on bottom tray | Open/closed via comparator | §7.5; drives pump lockout (latched, §11.4) |
| 6 | **Pump** | 24 V brushless DC submersible centrifugal, ≥1.0 m head, 80–240 L/h | <5 W typ, removable filter, 6/8 mm tubing | §7.3 preferred; quiet, continuous-rated |
| 7 | **Pump current sense** | INA219 (I²C) or shunt + amp on pump rail | mA resolution on 24 V/12 V rail | §7.5 **required** in V1 (DR-04 — clog/dry-run detection) |
| ~~8~~ | ~~**Fan**~~ | **REMOVED — no fan in V1** ([ECO-001](ECO-001-fan-removal.md)) | — | was §7.4 plant-circulation fan; LED is passively cooled (WI-EE-10), bay by open-frame convection |
| 9 | **Grow light** | Full-spectrum white hort LED **panel** (preferred at 150 mm clearance per PL-06), 50–80 W, PWM/0–10 V dim, remote driver | PPF 140–220 µmol/s, PPE ≥2.5 | §7.2/§16.3 — DR-01 now PASS; finalize per §4 |
| 10 | **RTC** | DS3231SN (battery-backed, I²C) + CR2032 | ±2 ppm TCXO | §16.1 / DR-05; placed away from driver heat (WI-EE-10 §6) |
| 11 | **Status LEDs** | 5 × WS2812B-2020 **or** 5 × discrete RGB + drivers | Dimmable, PWM night mode | §7.11; detailed in [WI-EE-09](WI-EE-09-status-led-board.md) |

## 2. PoC bench protocol

Run on an ESP32-S3 dev board + breadboard. Log to `electronics/test/poc-logs/` (template in §3).
Each test maps to a §15.3 M2 acceptance row.

| ID | Test | Method | Acceptance threshold |
|---|---|---|---|
| M2-01 | MCU | Flash blink + I²C/ADC bring-up sketch | Boots, all buses enumerate. **✔ (selection)** |
| M2-02 | Temp/RH | Log SHT40 vs a calibrated reference hygrometer, 2 h, 3 RH points | within ±1 °C and ±3 %RH vs reference; stable (no drift/spikes) |
| M2-03 | Moisture | Record raw ADC in **air**, **dry media**, **field-capacity media**, **saturated media** (the §7.6 model) | Four distinct, monotonic, repeatable raw values; normalized map spans 0–100 |
| M2-04 | Reservoir low | Fill/drain cycle; log switch transition vs water level | Reliable low-level edge; no chatter at threshold |
| M2-05 | Leak | Drip water across the trace pad; log signal + verify firmware pump-lockout hook | Detects within seconds; pump-enable line forced low; latches until manual clear |
| M2-06 | Pump | Run into a graduated cylinder for 30 s ×3; SPL meter @1 m | ml/s logged (±25 % repeatable, §7.3); ≤30 dBA @1 m |
| ~~M2-07~~ | ~~Fan~~ | **N/A — no fan in V1** ([ECO-001](ECO-001-fan-removal.md)) | — |
| M2-08 | LED dim | Drive dim input 25/50/75/100 %; measure PPFD grid with PAR meter at canopy plane | Monotonic PPFD map; values usable by [WI-PL-02 DLI calc](../../plan/work-items/01-plant-science/WI-PL-02-light-dli-targets.md) |
| — | Pump current | Log INA219 mA at idle / normal / blocked-intake / dry-run | Distinguishable current signatures for clog & dry-run (DR-04) |

## 3. Bench-log template

A ready-to-fill template is committed at
[`electronics/test/poc-logs/poc-log-template.csv`](../test/poc-logs/poc-log-template.csv):

```csv
test_id,component,part_no,date,operator,condition,measured_value,unit,reference_value,pass_fail,notes
M2-02,SHT40,SEN-SHT40,,,,,degC/%RH,,,
M2-06,pump,PMP-24-1m,,,30s_run_1,,ml,,,
```

## 4. Grow-light gate (§23 DR-01) — both halves now PASS

- **Thermal half — DONE (passive, no fan):** [WI-EE-10](WI-EE-10-thermal-budget-model.md) confirms
  the committed 60 W light is a clean **fan-less** GO on a `≤0.8 °C/W` passive heatsink (the bound the
  fixture must use); the passive ceiling is ~80 W and 100 W is full-yield-variant only (needs active
  cooling — [ECO-001](ECO-001-fan-removal.md)).
- **Photometric half — DONE (PASS):** [WI-PL-06](../../plan/work-items/01-plant-science/WI-PL-06-photometric-model.md)
  shows ≥0.6 uniformity and the §7.2 PPFD across the canopy. **Form-factor constraint:** a **panel**
  meets uniformity at the 150 mm clearance target, while a single **bar** only reaches ≥0.6 at
  ≥200–225 mm. The compact frame is height-constrained (DR-07), so the **panel form factor is
  preferred**; a bar is acceptable only if the mechanical mount allows ≥200 mm clearance.
- **§16.3 gate:** any candidate must publish real power draw, PPF/PPFD map, dimming method,
  horticultural spectrum, and thermal-mounting data — `scripts/bom_check.py` enforces this. No
  lumen-/"equivalent-watt"-only fixture passes.

DR-01 is clear, so the light may now be **finalized** by selecting a real fixture that meets the §16.3
data requirements **and** the PL-06 form-factor/clearance result. Pending that procurement pick, the
BOM carries a compliant **panel candidate** (`LIGHT-CANDIDATE-60W`) referencing the
[PL-06 PPFD maps](../../validation/ppfd-measurements/model/); the 100 W bar is the full-yield
[alternate](../bom/alternates.csv) (needs ≥200 mm clearance).

## 5. Deliverable status

| Deliverable | State |
|---|---|
| MCU selected + BOM entry | ✔ done |
| Temp/RH selection + protocol | ✔ selection / ⏳ bench log |
| Moisture selection + protocol | ✔ selection / ⏳ bench log |
| Reservoir-level selection + protocol | ✔ selection / ⏳ bench log |
| Leak selection + protocol | ✔ selection / ⏳ bench log |
| Pump selection + protocol | ✔ selection / ⏳ flow+noise log |
| ~~Fan selection + protocol~~ | **N/A — removed, no fan in V1 (ECO-001)** |
| LED dim selection + protocol | ✔ selection / ⏳ PPFD map |
| Grow-light §16.3 gating | ✔ DR-01 PASS (thermal ✔ EE-10 / photometric ✔ PL-06); panel form preferred |
| Grow-light BOM finalization | gate clear — panel candidate in BOM; final procurement pick outstanding |

⏳ = requires breadboard hardware (and, for PPFD, a PAR meter + the WI-PL-06 photometric model).

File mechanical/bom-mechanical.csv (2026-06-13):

ref | item | subsystem | qty | material | spec | removal | source | notes
ME-POT | Pot 10 L tapered | pot | 1 | Food-safe PP/PE | 250 mm top OD x 255 H; drain holes; ~9.7 L usable | Tool-free lift-out | Bought | 8-10 L compact band (§3.3); fits 268 mm interior depth with 18 mm clearance
ME-RES | Reservoir 4 L pull-out | reservoir | 1 | Food-safe PP/PETG | 240x150x125 mm; ~4.1 L usable; hand-cleanable opening | Tool-free drawer | Bought or printed PETG | Low-level line at 25 mm; sits below pot deck (146<180 mm)
ME-PUMP-CLIP | Pump retention clip | wet | 1 | PETG | Open-front C-cradle for 45 mm pump body; silicone iso pad | Tool-free | Printed | Rubber-isolated mount (§7.4/§8.7)
ME-LEAK-TRAY | Leak tray | wet | 1 | PETG | 440x300 mm; 24 mm rim; front overflow weir; sensor sump | n/a (fixed) | Printed | Catches all water; feeds leak sensor (§17.1)
ME-POT-TRAY | Pot tray | wet | 1 | PETG | 400x262 mm; locating ring + gutter drains + downspout | n/a (fixed) | Printed | Overflow falls to leak tray; pot kept out of standing water
ME-DRY-BAY | Electronics dry bay | dry | 1 | PETG/ASA | 420x170x92 mm tray; PCB + driver bosses; grommet entries | Lid lifts off (top) | Printed | Serviced without opening wet bay (§8.4)
ME-DRY-LID | Dry-bay lid | dry | 1 | PETG/ASA | 420x170 mm with drop lip + vents | Tool-free | Printed | Splash protection (§8.5)
ME-LIGHT-MOUNT | LED head carrier | light | 1 | ASA/ABS | Adjustable carrier; 6-step height row; tether eyelets | Tool (M3) | Printed | Secondary retention; 150-300 mm clearance (§7.2/§8.6); LED head bought (Light track)
ME-FAN-MOUNT | Fan mount + guard | grow | 1 | PETG/ASA | 92 mm fan plate; integral finger guard; grommet bores | Tool (M3) | Printed | Required guard; rubber grommets (§7.4)
ME-CABLE-CH | Cable/tube channel | routing | 1 | PETG | Divided wire|tube channel; strain-relief slots | Tool (M3) | Printed | Separates wiring from tube (§8.5)
ME-TUBE-CLIP | Tube clip (8 mm) | routing | 4 | PETG | Snap C-clip; 0.4 mm grip | Tool-free snap | Printed | Tubing inspectable/retained
ME-CABLE-CLIP | Cable saddle clip | routing | 6 | PETG | Open-top saddle for wire bundle | Tool-free | Printed | Cable management (§16.2 cable clips)
ME-SENSOR-CLIP | Moisture-probe clip | sensors | 1 | PETG | Replaceable clip at pot edge | Tool-free | Printed | Replaceable probe (§7.6/§8.4)
ME-DIFFUSER | Status LED diffuser | ui | 1 | Frosted PETG/acrylic | 140x14 mm; 5 light-pipe windows | Tool-free | Printed/cut | Front status UI (§3.4/§3.5)
ME-FRAME-EXT | Frame uprights+rails | frame | 1 | Aluminium 20x20 extrusion | 4 uprights @700 + top/mid/low rails | n/a | Bought + cut | Stable with full reservoir + plant (§16.2)
ME-FASTEN | Fasteners (wet zone) | fasteners | 1 | Stainless steel | M3 SHCS + heat-set inserts | n/a | Bought | Stainless near water (§8.3/§16.2)
ME-TUBE | Tubing | wet | 1 | Silicone/PVC | 6/8 mm food-safe; kink-resistant | Tool-free | Bought | Per §7.3/§16.2
ME-GROMMET | Cable grommets | routing | 3 | Rubber | 12 mm bore | Tool-free | Bought | Drip-loop entries (§8.5)
ME-FAN-GROMMET | Fan iso grommets | grow | 4 | Rubber | Anti-vibration | Tool-free | Bought | Acoustic isolation (§8.7)
ME-FEET | Levelling feet | frame | 4 | Rubber | 15 mm | Tool-free | Bought | Decouple frame from surface

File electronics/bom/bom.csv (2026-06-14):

ref | item | category | subsystem | qty | value | part_no | manufacturer | package | spec_ref | power_w | ppf_or_ppfd | dimming | spectrum | thermal_mounting | electrical_cert | status | notes
U1 | ESP32-S3-WROOM-1 | mcu | control | 1 | N8R8 | ESP32-S3-WROOM-1-N8R8 | Espressif | module | §7.1/§16.1 |  |  |  |  |  |  | committed | octal flash+PSRAM; GPIO26-37 reserved
U2 | Temp/RH sensor | sensor | climate | 1 | SHT40 | SHT40-AD1B | Sensirion | DFN | §7.5/§16.1 |  |  |  |  |  |  | committed | I2C 0x44; on cabled breakout
U3 | RTC | timekeeping | control | 1 | DS3231SN | DS3231SN | Analog Devices | SOIC | §16.1/DR-05 |  |  |  |  |  |  | committed | battery-backed; place away from driver heat
BT1 | RTC coin cell + holder | timekeeping | control | 1 | CR2032 | CR2032+holder | generic | TH | §16.1 |  |  |  |  |  |  | committed | RTC backup
U4 | Pump current monitor | sensor | irrigation | 1 | INA219 | INA219AIDR | Texas Instruments | SOIC | §7.5/DR-04 |  |  |  |  |  |  | committed | clog/dry-run detection (required V1)
U5 | Leak comparator | protection | irrigation | 1 | LM393 | LM393DR | Texas Instruments | SOIC | §7.5 |  |  |  |  |  |  | committed | clean debounced leak edge
Q1 | Pump MOSFET | power | irrigation | 1 | logic-level N-FET | DMN3404L | Diodes Inc | SOT23 | §7.10/§9.6 |  |  |  |  |  |  | committed | fails OFF via R-pulldown
R1 | Gate pulldown | power | irrigation | 1 | 10k | RC0603-10k | generic | 0603 | §9.6/§11.4 |  |  |  |  |  |  | committed | pump gate->GND fail-OFF
R2 | Gate series | power | irrigation | 1 | 100R | RC0603-100R | generic | 0603 | §7.10 |  |  |  |  |  |  | committed
F1 | Input fuse + holder | protection | power | 1 | 6.3A slow | fuse-6p3A | generic | 5x20mm | §7.8/§11.4 |  |  |  |  |  |  | committed | 8A variant for 150W build
Q2 | Reverse-polarity P-FET | protection | power | 1 | P-FET 40V | DMP3056L | Diodes Inc | SOT23 | §17.1 |  |  |  |  |  |  | committed | high-side; Zener-clamped gate
D1 | Input TVS | protection | power | 1 | SMBJ28A | SMBJ28A | Littelfuse | SMB | §17.1 |  |  |  |  |  |  | committed | 28V standoff
D2 | Pump flyback | protection | irrigation | 1 | Schottky 3A | SS34 | generic | SMC | §17.1 |  |  |  |  |  |  | committed
U6 | 24->12V buck | power | power | 1 | 2A | TPS5430 | Texas Instruments | SOIC | §7.8 |  |  |  |  |  |  | optional | 12V pump option only (no fan in V1 | ECO-001); omit if 24V pump used
U7 | 24->5V buck | power | power | 1 | 2A | TPS5430 | Texas Instruments | SOIC | §7.8 |  |  |  |  |  |  | committed | sensors/status/3V3 feed
U8 | 5->3.3V reg | power | power | 1 | 1A | AP2112K-3.3 | Diodes Inc | SOT23-5 | §7.8 |  |  |  |  |  |  | committed | MCU rail
U9 | LED dim buffer | interface | light | 1 | opamp | MCP6001 | Microchip | SOT23-5 | §7.2 |  |  |  |  |  |  | optional-dnp | NOT NEEDED - LDD-H driver takes logic-level 3.3V PWM directly (component-sourcing.md); remove in follow-up
CN_PWR | Power input connector | connector | power | 1 | XT30 | XT30PW | generic | TH | §7.10 |  |  |  |  |  |  | committed | >=10A
CN_LED | LED connector | connector | light | 1 | JST VH 4 | B4PS-VH | JST | TH | §7.9 |  |  |  |  |  |  | committed | +24V/GND/DIM/NTC
CN_PUMP | Pump connector | connector | irrigation | 1 | JST VH 2 | B2PS-VH | JST | TH | §7.9 |  |  |  |  |  |  | committed
CN_FAN | Fan connector | connector | climate | 1 | 4-pin fan | 47053-1000 | Molex | TH | §7.9 |  |  |  |  |  |  | optional-dnp | no fan in V1 (ECO-001); PWM+tach header kept DNP for future fan-drive option
CN_MOIST | Moisture connector | connector | irrigation | 1 | JST PH 3 | B3B-PH | JST | TH | §7.9 |  |  |  |  |  |  | committed | replaceable probe
CN_RES | Reservoir connector | connector | irrigation | 1 | JST PH 3 | B3B-PH | JST | TH | §7.9 |  |  |  |  |  |  | committed
CN_LEAK | Leak connector | connector | irrigation | 1 | JST PH 2 | B2B-PH | JST | TH | §7.9 |  |  |  |  |  |  | committed
CN_SENS | Sensor/I2C connector | connector | climate | 1 | JST PH 4 | B4B-PH | JST | TH | §7.9 |  |  |  |  |  |  | committed | SHT40
CN_STATUS | Status LED connector | connector | ui | 1 | JST XH 3 | B3B-XH | JST | TH | §7.9/§7.11 |  |  |  |  |  |  | committed | 5V/GND/DATA
CN_DBG | Debug UART header | connector | control | 1 | 2.54 4-pin | header-4 | generic | TH | §7.9 |  |  |  |  |  |  | committed | service only
CN_USB | USB-C receptacle | connector | control | 1 | USB-C | USB4105 | GCT | SMD | §7.9 |  |  |  |  |  |  | committed | USB-CDC flash/log
PCB1 | Controller PCB | pcb | control | 1 | 4-layer | opencanopy-ctrl | inhouse | board | §7.9 |  |  |  |  |  |  | pending-cad | fab from netlist (tscircuit flow)
M1 | Pump (24V submersible) | actuator | irrigation | 1 | 24V IP68 brushless | TL-B03H | TOPSFLO | module | §7.3 |  |  |  |  |  |  | committed | brushless centrifugal IP68 submersible food-grade >20000h; 2.5m max head/390 L/h -> <5W at ~1m op point; 2-wire FET-switched (see component-sourcing.md)
SEN1 | Capacitive moisture probe | sensor | irrigation | 1 | v2 coated | SEN-CAP-V2 | generic | module | §7.6 |  |  |  |  |  |  | committed | corrosion-resistant; replaceable
SEN2 | Reservoir float switch | sensor | irrigation | 1 | low-level | SEN-FLOAT-LOW | generic | module | §7.7 |  |  |  |  |  |  | committed
SEN3 | Leak trace/rope | sensor | irrigation | 1 | tray | SEN-LEAK-TRACE | generic | module | §7.5 |  |  |  |  |  |  | committed
LED_PANEL | Grow light (compact) | light | light | 1 | ~60W LM301H board | LM301H-board-60W | Samsung LED diodes + board vendor | panel | §7.2/§16.3 | 60 | avg ~450 / min ~325 umol/m2/s @150mm unif>=0.64 (PPF ~150 umol/s; see validation/ppfd-measurements/model/ppfd-map-c-150mm.csv) | PWM 100Hz-1kHz via LDD-H driver | full-spectrum white 3000-3500K LM301H + 660nm deep red horticultural | passive aluminum heatsink; DC-DC LDD driver in upper dry bay | CE/UL (board+driver) | CANDIDATE-DR01-PASS | LM301H/EVO board PPE 2.7-3.1; finalize SKU vs published PPFD map (PL-06); driver = U_LED_DRV (see component-sourcing.md)
LED_STATUS | Status LED board parts (5x WS2812B) | ui | ui | 5 | WS2812B-2020 | WS2812B-2020 | Worldsemi | 2020 | §7.11 |  |  |  |  |  |  | committed | front-panel; LCSC C965555 / JLCPCB stock; 3.7-5.3V (validates 4.5V design); see WI-EE-09
PCB2 | Status LED PCB | pcb | ui | 1 | 2-layer | opencanopy-status | inhouse | board | §7.11 |  |  |  |  |  |  | pending-cad | fab from netlist (tscircuit flow)
PSU1 | External 24VDC PSU | power | power | 1 | 120W (150W@100W LED) | PSU-24-120 | generic | brick | §7.8/§16.1 |  |  |  |  |  | CE/UL | committed | certified external brick; not inside unit
C2 C3 C_EN C_RTC C_INA C_U5 C_LK C_BULK3 | Decoupling/bypass capacitor | passive | power | 8 | 100nF | CL05B104KO5NNNC | Samsung | 0402 | §7.9 |  |  |  |  |  |  | committed | per-IC 100nF + 24V HF bypass (netlist)
C1 | MCU 3V3 bulk cap | passive | control | 1 | 22uF | GRM21BR61A226ME | Murata | 0805 | §7.8 |  |  |  |  |  |  | committed | ESP32-S3 rail bulk
C_OUT5 | 5V buck output cap | passive | power | 1 | 22uF | GRM31CR61E226KE | Murata | 1210 | §7.8 |  |  |  |  |  |  | committed | U7 output
C_BULK2 C_IN5 | 24V bulk / buck input ceramic | passive | power | 2 | 10uF | GRM31CR71H106KA | Murata | 1206 | §7.8 |  |  |  |  |  |  | committed | 50V rated
C_IN33 C_OUT33 | 3V3 LDO in/out cap | passive | power | 2 | 1uF | CL05A105KO5NNNC | Samsung | 0402 | §7.8 |  |  |  |  |  |  | committed | U8 in/out
C_BT5 C_MOIST | buck boot / moisture filter cap | passive | mixed | 2 | 10nF | CL05B103KB5NNNC | Samsung | 0402 | §7.8 |  |  |  |  |  |  | committed | U7 BOOT + moisture RC
C_BULK1 | 24V bulk electrolytic | passive | power | 1 | 100uF | EEHZA1H101P | Panasonic | CP_Elec_8x10 | §7.8 |  |  |  |  |  |  | committed | low-ESR; pump inrush
R_EN R_LK_RA R_LK_RB R_LK_OUT | Resistor 10k | passive | mixed | 4 | 10k | RC0402FR-0710K | Yageo | 0402 | §7.9 |  |  |  |  |  |  | committed | EN pull-up + leak divider + OC pull-up
R_SDA R_SCL | I2C pull-up | passive | control | 2 | 4.7k | RC0402FR-074K7 | Yageo | 0402 | §7.5 |  |  |  |  |  |  | committed | SDA/SCL to 3V3
R_LK_PU R_RP | Resistor 100k | passive | mixed | 2 | 100k | RC0402FR-07100K | Yageo | 0402 | §17.1 |  |  |  |  |  |  | committed | leak-trace pull-up + Q2 gate R
R_MOIST | Moisture series R | passive | irrigation | 1 | 1k | RC0402FR-071K | Yageo | 0402 | §7.6 |  |  |  |  |  |  | committed | ADC series
R_DIM | LED dim series R | passive | light | 1 | 100R | RC0402FR-07100R | Yageo | 0402 | §7.2 |  |  |  |  |  |  | committed | PWM-direct dim
R_DATA | WS2812 data series R | passive | ui | 1 | 330R | RC0402FR-07330R | Yageo | 0402 | §7.11 |  |  |  |  |  |  | committed | status data line
R_FB5A | 5V buck feedback top | passive | power | 1 | 22k | RC0402FR-0722K | Yageo | 0402 | §7.8 |  |  |  |  |  |  | committed | TPS5430 Vsense
R_FB5B | 5V buck feedback bottom | passive | power | 1 | 7.15k | RC0402FR-077K15 | Yageo | 0402 | §7.8 |  |  |  |  |  |  | committed | TPS5430 Vsense
L5 | 5V buck inductor | passive | power | 1 | 10uH | SRP1245A-100M | Bourns | L_12x12 | §7.8 |  |  |  |  |  |  | committed | >=3A saturation
D_CAT5 | 5V buck catch diode | protection | power | 1 | B340A | B340A | Diodes Inc | SMC | §7.8 |  |  |  |  |  |  | committed | 3A 40V Schottky
DZ_RP | Reverse-pol gate Zener | protection | power | 1 | 15V | BZT52C15 | Diodes Inc | SOD-323 | §17.1 |  |  |  |  |  |  | committed | Q2 V_GS clamp
R_SHUNT | Pump current shunt | passive | irrigation | 1 | 0.1R | CSS2H-2512R-L100F | Bourns | 2512 | §7.5/DR-04 |  |  |  |  |  |  | committed | INA219 sense; 1W
SW1 SW2 | Boot/reset buttons | switch | control | 2 | tact | TS-1187 | generic | SW_SPST_SMD | §7.9 |  |  |  |  |  |  | committed | hidden in normal use
C_IN12 C_OUT12 C_BT12 L12 D_CAT12 R_FB12A R_FB12B | 12V buck support (DNP option) | passive | power | 7 | assorted | see-netlist | various | mixed | §7.8 |  |  |  |  |  |  | optional-dnp | 12V pump alternate only; no fan in V1 (ECO-001)
R_NTC | LED NTC divider top (DNP) | passive | light | 1 | 10k | RC0402FR-0710K | Yageo | 0402 | §7.2/DR-09 |  |  |  |  |  |  | optional-dnp | fit with optional LED-heatsink NTC
R_DIMF C_DIMF | 0-10V dim RC (DNP) | passive | light | 2 | assorted | see-netlist | various | 0402 | §7.2 |  |  |  |  |  |  | optional-dnp | with U9 op-amp; PWM-direct is default
R_FANG R_TACH | Fan PWM/tach provision (DNP) | passive | climate | 2 | assorted | see-netlist | various | 0402 | §7.4 |  |  |  |  |  |  | optional-dnp | no fan in V1 (ECO-001); 4-pin PWM provision
J_EXP J_CAM | Expansion headers (DNP) | connector | control | 2 | header | PinHeader | generic | TH | §4.3 |  |  |  |  |  |  | optional-dnp | camera/PAR/pH-EC/load-cell; unpopulated V1
U_LED_DRV | LED constant-current driver | power | light | 3 | LDD-1000H | LDD-1000H | Mean Well | SIP-6 | §7.2 |  |  |  |  |  |  | committed | DC-DC CC step-down from 24V rail (9-56Vin); logic-level PWM dim 2.5-6V 100Hz-1kHz (3.3V direct); ~3x for 60W; STEP from Mean Well
W1 | Silicone hook-up wire | cable | wiring | 1 | 18/20/26 AWG | silicone-UL3239 | generic | wire | §8.5 |  |  |  |  |  |  | committed | 18AWG power / 20AWG pump / 26-28AWG signal; flexible silicone (wet zone); to chosen JST/XT30 housings

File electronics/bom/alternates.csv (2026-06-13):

replaces_ref | item | part_no | manufacturer | spec_ref | power_w | ppf_or_ppfd | dimming | spectrum | thermal_mounting | electrical_cert | notes
U1 | ESP32-C6 module | ESP32-C6-WROOM-1 | Espressif | §7.1 |  |  |  |  |  |  | acceptable; adds Thread/Matter | fewer IO
U2 | Temp/RH SHT31 | SHT31-DIS-B | Sensirion | §7.5 |  |  |  |  |  |  | SHT3x-class equivalent
U3 | RTC RV-3028 | RV-3028-C7 | Micro Crystal | §16.1 |  |  |  |  |  |  | ultra-low-power alt to DS3231
Q1 | Pump MOSFET alt | CSD18540 | Texas Instruments | §7.10 |  |  |  |  |  |  | higher current headroom
M1 | Pump (12V) | PMP-12-1m | generic | §7.3 |  |  |  |  |  |  | uses 12V rail; size 12V buck >=2A
LED_STATUS | Discrete RGB + driver | TLC59116 | Texas Instruments | §7.11 |  |  |  |  |  |  | I2C constant-current alt to WS2812 (avoids 5V data-level issue)
U6 | 24->12V buck alt | LMR33630 | Texas Instruments | §7.8 |  |  |  |  |  |  | higher efficiency
LED_PANEL | Grow light (full-yield 100W bar) | LIGHT-CANDIDATE-100W | generic-hort | §7.2/§16.3 | 100 | avg ~838 / min ~507 umol/m2/s @200mm unif 0.61 (PPF ~220 umol/s; bar form) | PWM + 0-10V | full-spectrum white 3500K + 660nm horticultural | remote heatsink driver; requires <=0.60 C/W heatsink (WI-EE-10) | CE/UL listed | full-yield variant only; DR-01 GO-with-mitigation; bar needs >=200mm clearance for >=0.6 unif (PL-06 cfg D)
LED_PANEL | Grow light (compact bar alt) | LIGHT-CANDIDATE-60W-BAR | generic-hort | §7.2/§16.3 | 60 | avg ~513 / min ~327 umol/m2/s @225mm unif 0.64 (PPF ~150 umol/s; bar form) | PWM + 0-10V | full-spectrum white 3500K + 660nm horticultural | remote heatsink driver | CE/UL listed | bar alternative to the panel; needs >=225mm clearance for >=0.6 unif (PL-06 cfg B)
SEN2 | Reservoir analog level | eTape-PN-12110215TC-12 | Milone | §7.7 |  |  |  |  |  |  | optional analog level on RES_LEVEL_ADC

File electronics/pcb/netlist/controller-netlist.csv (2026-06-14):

net | ref | pin | populated | part
+24V_IN | J_PWR | 1 | Y | XT30PW
+24V_IN | F1 | 1 | Y | fuse-6p3A
+24V_FUSED | F1 | 2 | Y | fuse-6p3A
+24V_FUSED | Q2 | S | Y | DMP3056L
+24V_FUSED | DZ_RP | K | Y | BZT52-15V
RP_GATE | Q2 | G | Y | DMP3056L
RP_GATE | DZ_RP | A | Y | BZT52-15V
RP_GATE | R_RP | 1 | Y | R-100k
+24V | Q2 | D | Y | DMP3056L
+24V | D1 | K | Y | SMBJ28A
+24V | C_BULK1 | + | Y | 100uF-50V
+24V | C_BULK2 | 1 | Y | 10uF-50V
+24V | C_BULK3 | 1 | Y | C-100nF
+24V | U6 | VIN | DNP | TPS5430DDA
+24V | U6 | ENA | DNP | TPS5430DDA
+24V | C_IN12 | 1 | DNP | 10uF-50V
+24V | U7 | VIN | Y | TPS5430DDA
+24V | U7 | ENA | Y | TPS5430DDA
+24V | C_IN5 | 1 | Y | 10uF-50V
+24V | J_LED | 1 | Y | B4PS-VH
+24V | R_SHUNT | 1 | Y | R-0R1-1W
+24V | U4 | IN+ | Y | INA219AIDR
PUMP_+ | R_SHUNT | 2 | Y | R-0R1-1W
PUMP_+ | U4 | IN- | Y | INA219AIDR
PUMP_+ | J_PUMP | 1 | Y | B2PS-VH
PUMP_+ | D2 | K | Y | SS34
PUMP_RET | J_PUMP | 2 | Y | B2PS-VH
PUMP_RET | Q1 | D | Y | DMN3404L
PUMP_RET | D2 | A | Y | SS34
PUMP_GATE | Q1 | G | Y | DMN3404L
PUMP_GATE | R2 | 2 | Y | R-100R
PUMP_GATE | R1 | 1 | Y | R-10k
PH12 | U6 | PH | DNP | TPS5430DDA
PH12 | L12 | 1 | DNP | 15uH-3A
PH12 | D_CAT12 | K | DNP | B340A
PH12 | C_BT12 | 2 | DNP | C-10nF
+12V | L12 | 2 | DNP | 15uH-3A
+12V | C_OUT12 | 1 | DNP | 22uF-25V
+12V | R_FB12A | 1 | DNP | R-68k
+12V | J_FAN | 2 | DNP | 47053-1000
FB12 | U6 | VSENSE | DNP | TPS5430DDA
FB12 | R_FB12A | 2 | DNP | R-68k
FB12 | R_FB12B | 1 | DNP | R-7k5
BOOT12 | U6 | BOOT | DNP | TPS5430DDA
BOOT12 | C_BT12 | 1 | DNP | C-10nF
PH5 | U7 | PH | Y | TPS5430DDA
PH5 | L5 | 1 | Y | 10uH-3A
PH5 | D_CAT5 | K | Y | B340A
PH5 | C_BT5 | 2 | Y | C-10nF
+5V | L5 | 2 | Y | 10uH-3A
+5V | C_OUT5 | 1 | Y | 22uF-25V
+5V | R_FB5A | 1 | Y | R-22k
+5V | U8 | VIN | Y | AP2112K-3.3
+5V | U8 | EN | Y | AP2112K-3.3
+5V | C_IN33 | 1 | Y | C-1uF
+5V | J_STATUS | 1 | Y | B3B-XH
FB5 | U7 | VSENSE | Y | TPS5430DDA
FB5 | R_FB5A | 2 | Y | R-22k
FB5 | R_FB5B | 1 | Y | R-7k15
BOOT5 | U7 | BOOT | Y | TPS5430DDA
BOOT5 | C_BT5 | 1 | Y | C-10nF
+3V3 | U8 | VOUT | Y | AP2112K-3.3
+3V3 | C_OUT33 | 1 | Y | C-1uF
+3V3 | U1 | 3V3 | Y | ESP32-S3-WROOM-1-N8R8
+3V3 | C1 | 1 | Y | GRM21-22uF-10V
+3V3 | C2 | 1 | Y | C-100nF
+3V3 | C3 | 1 | Y | C-100nF
+3V3 | R_EN | 1 | Y | R-10k
+3V3 | R_SDA | 1 | Y | R-4k7
+3V3 | R_SCL | 1 | Y | R-4k7
+3V3 | U3 | VCC | Y | DS3231SN
+3V3 | C_RTC | 1 | Y | C-100nF
+3V3 | U4 | VS | Y | INA219AIDR
+3V3 | C_INA | 1 | Y | C-100nF
+3V3 | U5 | VCC | Y | LM393DR
+3V3 | C_U5 | 1 | Y | C-100nF
+3V3 | R_LK_PU | 1 | Y | R-100k
+3V3 | R_LK_RA | 1 | Y | R-10k
+3V3 | R_LK_OUT | 1 | Y | R-10k
+3V3 | R_NTC | 1 | DNP | R-10k
+3V3 | R_TACH | 2 | DNP | R-10k
+3V3 | J_MOIST | 1 | Y | B3B-PH
+3V3 | J_SENS | 1 | Y | B4B-PH
+3V3 | J_DBG | 1 | Y | header-4
GND | J_PWR | 2 | Y | XT30PW
GND | D1 | A | Y | SMBJ28A
GND | C_BULK1 | - | Y | 100uF-50V
GND | C_BULK2 | 2 | Y | 10uF-50V
GND | C_BULK3 | 2 | Y | C-100nF
GND | U1 | GND | Y | ESP32-S3-WROOM-1-N8R8
GND | C1 | 2 | Y | GRM21-22uF-10V
GND | C2 | 2 | Y | C-100nF
GND | C3 | 2 | Y | C-100nF
GND | C_EN | 2 | Y | C-100nF
GND | SW1 | 2 | Y | SW-TACT
GND | SW2 | 2 | Y | SW-TACT
GND | U3 | GND | Y | DS3231SN
GND | C_RTC | 2 | Y | C-100nF
GND | BT1 | - | Y | CR2032+holder
GND | U4 | GND | Y | INA219AIDR
GND | C_INA | 2 | Y | C-100nF
GND | U4 | A0 | Y | INA219AIDR
GND | U4 | A1 | Y | INA219AIDR
GND | U5 | GND | Y | LM393DR
GND | C_U5 | 2 | Y | C-100nF
GND | R_LK_RB | 2 | Y | R-10k
GND | C_LK | 2 | Y | C-100nF
GND | U5 | IN2+ | Y | LM393DR
GND | U5 | IN2- | Y | LM393DR
GND | C_MOIST | 2 | Y | C-10nF
GND | U6 | GND | DNP | TPS5430DDA
GND | C_IN12 | 2 | DNP | 10uF-50V
GND | C_OUT12 | 2 | DNP | 22uF-25V
GND | R_FB12B | 2 | DNP | R-7k5
GND | D_CAT12 | A | DNP | B340A
GND | U7 | GND | Y | TPS5430DDA
GND | C_IN5 | 2 | Y | 10uF-50V
GND | C_OUT5 | 2 | Y | 22uF-25V
GND | R_FB5B | 2 | Y | R-7k15
GND | D_CAT5 | A | Y | B340A
GND | U8 | GND | Y | AP2112K-3.3
GND | C_IN33 | 2 | Y | C-1uF
GND | C_OUT33 | 2 | Y | C-1uF
GND | Q1 | S | Y | DMN3404L
GND | R1 | 2 | Y | R-10k
GND | R_RP | 2 | Y | R-100k
GND | U9 | V- | DNP | MCP6001
GND | C_DIMF | 2 | DNP | C-1uF
GND | J_LED | 2 | Y | B4PS-VH
GND | J_FAN | 1 | DNP | 47053-1000
GND | J_MOIST | 2 | Y | B3B-PH
GND | J_RES | 2 | Y | B3B-PH
GND | J_LEAK | 2 | Y | B2B-PH
GND | J_SENS | 2 | Y | B4B-PH
GND | J_STATUS | 2 | Y | B3B-XH
GND | J_DBG | 4 | Y | header-4
GND | J_USB | GND | Y | USB4105
GND | J_USB | SHIELD | Y | USB4105
SDA | U1 | IO8 | Y | ESP32-S3-WROOM-1-N8R8
SDA | R_SDA | 2 | Y | R-4k7
SDA | U3 | SDA | Y | DS3231SN
SDA | U4 | SDA | Y | INA219AIDR
SDA | J_SENS | 3 | Y | B4B-PH
SCL | U1 | IO9 | Y | ESP32-S3-WROOM-1-N8R8
SCL | R_SCL | 2 | Y | R-4k7
SCL | U3 | SCL | Y | DS3231SN
SCL | U4 | SCL | Y | INA219AIDR
SCL | J_SENS | 4 | Y | B4B-PH
VBAT | U3 | VBAT | Y | DS3231SN
VBAT | BT1 | + | Y | CR2032+holder
EN | U1 | EN | Y | ESP32-S3-WROOM-1-N8R8
EN | R_EN | 2 | Y | R-10k
EN | C_EN | 1 | Y | C-100nF
EN | SW2 | 1 | Y | SW-TACT
IO0_BOOT | U1 | IO0 | Y | ESP32-S3-WROOM-1-N8R8
IO0_BOOT | SW1 | 1 | Y | SW-TACT
MOIST_SIG | J_MOIST | 3 | Y | B3B-PH
MOIST_SIG | R_MOIST | 1 | Y | R-1k
MOIST_ADC | R_MOIST | 2 | Y | R-1k
MOIST_ADC | C_MOIST | 1 | Y | C-10nF
MOIST_ADC | U1 | IO4 | Y | ESP32-S3-WROOM-1-N8R8
RES_LOW_SW | U1 | IO5 | Y | ESP32-S3-WROOM-1-N8R8
RES_LOW_SW | J_RES | 1 | Y | B3B-PH
RES_LEVEL_ADC | U1 | IO6 | Y | ESP32-S3-WROOM-1-N8R8
RES_LEVEL_ADC | J_RES | 3 | Y | B3B-PH
LEAK_SENSE | J_LEAK | 1 | Y | B2B-PH
LEAK_SENSE | R_LK_PU | 2 | Y | R-100k
LEAK_SENSE | U5 | IN1+ | Y | LM393DR
LEAK_SENSE | C_LK | 1 | Y | C-100nF
LEAK_REF | U5 | IN1- | Y | LM393DR
LEAK_REF | R_LK_RA | 2 | Y | R-10k
LEAK_REF | R_LK_RB | 1 | Y | R-10k
LEAK_DET | U5 | OUT1 | Y | LM393DR
LEAK_DET | R_LK_OUT | 2 | Y | R-10k
LEAK_DET | U1 | IO7 | Y | ESP32-S3-WROOM-1-N8R8
LED_NTC | J_LED | 4 | Y | B4PS-VH
LED_NTC | U1 | IO2 | Y | ESP32-S3-WROOM-1-N8R8
LED_NTC | R_NTC | 2 | DNP | R-10k
PUMP_PWM | U1 | IO10 | Y | ESP32-S3-WROOM-1-N8R8
PUMP_PWM | R2 | 1 | Y | R-100R
LED_DIM | U1 | IO14 | Y | ESP32-S3-WROOM-1-N8R8
LED_DIM | R_DIM | 1 | Y | R-100R
LED_DIM_OUT | R_DIM | 2 | Y | R-100R
LED_DIM_OUT | J_LED | 3 | Y | B4PS-VH
LED_DIM_OUT | U9 | OUT | DNP | MCP6001
LED_DIM_OUT | U9 | IN- | DNP | MCP6001
DIM_FILT | R_DIMF | 2 | DNP | R-10k
DIM_FILT | C_DIMF | 1 | DNP | C-1uF
DIM_FILT | U9 | IN+ | DNP | MCP6001
DIM_PWM_TAP | R_DIMF | 1 | DNP | R-10k
U9_VDD | U9 | V+ | DNP | MCP6001
STATUS_DATA | U1 | IO21 | Y | ESP32-S3-WROOM-1-N8R8
STATUS_DATA | R_DATA | 1 | Y | R-330R
STATUS_DATA_OUT | R_DATA | 2 | Y | R-330R
STATUS_DATA_OUT | J_STATUS | 3 | Y | B3B-XH
USB_DM | U1 | IO19 | Y | ESP32-S3-WROOM-1-N8R8
USB_DM | J_USB | D- | Y | USB4105
USB_DP | U1 | IO20 | Y | ESP32-S3-WROOM-1-N8R8
USB_DP | J_USB | D+ | Y | USB4105
VBUS | J_USB | VBUS | Y | USB4105
UART_TX | U1 | IO43 | Y | ESP32-S3-WROOM-1-N8R8
UART_TX | J_DBG | 2 | Y | header-4
UART_RX | U1 | IO44 | Y | ESP32-S3-WROOM-1-N8R8
UART_RX | J_DBG | 3 | Y | header-4
FAN_PWM | U1 | IO12 | Y | ESP32-S3-WROOM-1-N8R8
FAN_PWM | R_FANG | 1 | DNP | R-100R
FAN_PWM_OUT | R_FANG | 2 | DNP | R-100R
FAN_PWM_OUT | J_FAN | 3 | DNP | 47053-1000
FAN_TACH | U1 | IO13 | Y | ESP32-S3-WROOM-1-N8R8
FAN_TACH | R_TACH | 1 | DNP | R-10k
FAN_TACH | J_FAN | 4 | DNP | 47053-1000
EXP_HX711_DT | U1 | IO15 | Y | ESP32-S3-WROOM-1-N8R8
EXP_HX711_DT | J_EXP | 1 | DNP | header-6
EXP_HX711_SCK | U1 | IO16 | Y | ESP32-S3-WROOM-1-N8R8
EXP_HX711_SCK | J_EXP | 2 | DNP | header-6
EXP_GP1 | U1 | IO17 | Y | ESP32-S3-WROOM-1-N8R8
EXP_GP1 | J_EXP | 3 | DNP | header-6
EXP_GP2 | U1 | IO18 | Y | ESP32-S3-WROOM-1-N8R8
EXP_GP2 | J_EXP | 4 | DNP | header-6
EXP_CAM1 | U1 | IO47 | Y | ESP32-S3-WROOM-1-N8R8
EXP_CAM1 | J_CAM | 1 | DNP | header-2
EXP_CAM2 | U1 | IO48 | Y | ESP32-S3-WROOM-1-N8R8
EXP_CAM2 | J_CAM | 2 | DNP | header-2
S_+5V | J_STA | 1 | Y | B3B-XH
S_+5V | D_LVD | A | Y | 1N5817
S_+5V | C_LBULK | 1 | Y | 10uF-10V
S_VLED | D_LVD | K | Y | 1N5817
S_VLED | LED1 | VDD | Y | WS2812B-2020
S_VLED | LED2 | VDD | Y | WS2812B-2020
S_VLED | LED3 | VDD | Y | WS2812B-2020
S_VLED | LED4 | VDD | Y | WS2812B-2020
S_VLED | LED5 | VDD | Y | WS2812B-2020
S_VLED | C_L1 | 1 | Y | C-100nF
S_VLED | C_L2 | 1 | Y | C-100nF
S_VLED | C_L3 | 1 | Y | C-100nF
S_VLED | C_L4 | 1 | Y | C-100nF
S_VLED | C_L5 | 1 | Y | C-100nF
S_GND | J_STA | 2 | Y | B3B-XH
S_GND | C_LBULK | 2 | Y | 10uF-10V
S_GND | LED1 | GND | Y | WS2812B-2020
S_GND | LED2 | GND | Y | WS2812B-2020
S_GND | LED3 | GND | Y | WS2812B-2020
S_GND | LED4 | GND | Y | WS2812B-2020
S_GND | LED5 | GND | Y | WS2812B-2020
S_GND | C_L1 | 2 | Y | C-100nF
S_GND | C_L2 | 2 | Y | C-100nF
S_GND | C_L3 | 2 | Y | C-100nF
S_GND | C_L4 | 2 | Y | C-100nF
S_GND | C_L5 | 2 | Y | C-100nF
S_DIN | J_STA | 3 | Y | B3B-XH
S_DIN | LED1 | DIN | Y | WS2812B-2020
S_D12 | LED1 | DOUT | Y | WS2812B-2020
S_D12 | LED2 | DIN | Y | WS2812B-2020
S_D23 | LED2 | DOUT | Y | WS2812B-2020
S_D23 | LED3 | DIN | Y | WS2812B-2020
S_D34 | LED3 | DOUT | Y | WS2812B-2020
S_D34 | LED4 | DIN | Y | WS2812B-2020
S_D45 | LED4 | DOUT | Y | WS2812B-2020
S_D45 | LED5 | DIN | Y | WS2812B-2020
S_D5OUT | LED5 | DOUT | Y | WS2812B-2020

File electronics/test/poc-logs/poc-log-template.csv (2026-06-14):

test_id | component | part_no | date | operator | condition | measured_value | unit | reference_value | pass_fail | notes
M2-01 | esp32s3-devkitc-1 | MCU-ESP32S3-N8R8 |  |  | boot+bus-enumerate |  | bool |  |  | all I2C/ADC buses up
M2-02 | sht40 | SEN-SHT40 |  |  | ambient |  | degC |  |  | vs calibrated reference
M2-02 | sht40 | SEN-SHT40 |  |  | ambient |  | %RH |  |  | vs calibrated reference
M2-03 | moisture | SEN-CAP-V2 |  |  | raw_air |  | adc |  |  | §7.6 calibration model
M2-03 | moisture | SEN-CAP-V2 |  |  | raw_dry_media |  | adc
M2-03 | moisture | SEN-CAP-V2 |  |  | raw_field_capacity |  | adc
M2-03 | moisture | SEN-CAP-V2 |  |  | raw_saturated |  | adc
M2-04 | reservoir-float | SEN-FLOAT-LOW |  |  | low-level-edge |  | bool |  |  | fill/drain cycle
M2-05 | leak | SEN-LEAK-TRACE |  |  | wet-detect |  | bool |  |  | verify pump lockout + latch
M2-06 | pump | PMP-24-1m |  |  | 30s_run_1 |  | ml |  |  | into graduated cylinder
M2-06 | pump | PMP-24-1m |  |  | 30s_run_2 |  | ml
M2-06 | pump | PMP-24-1m |  |  | 30s_run_3 |  | ml
M2-06 | pump | PMP-24-1m |  |  | noise_1m |  | dBA |  |  | SPL meter @1 m
M2-08 | grow-light | LIGHT-TBD-DR01 |  |  | ppfd_25pct |  | umol/m2/s |  |  | PAR meter at canopy plane
M2-08 | grow-light | LIGHT-TBD-DR01 |  |  | ppfd_50pct |  | umol/m2/s
M2-08 | grow-light | LIGHT-TBD-DR01 |  |  | ppfd_75pct |  | umol/m2/s
M2-08 | grow-light | LIGHT-TBD-DR01 |  |  | ppfd_100pct |  | umol/m2/s
DR04 | pump-current | SEN-INA219 |  |  | idle |  | mA |  |  | clog/dry-run signature
DR04 | pump-current | SEN-INA219 |  |  | normal |  | mA
DR04 | pump-current | SEN-INA219 |  |  | blocked_intake |  | mA
DR04 | pump-current | SEN-INA219 |  |  | dry_run |  | mA

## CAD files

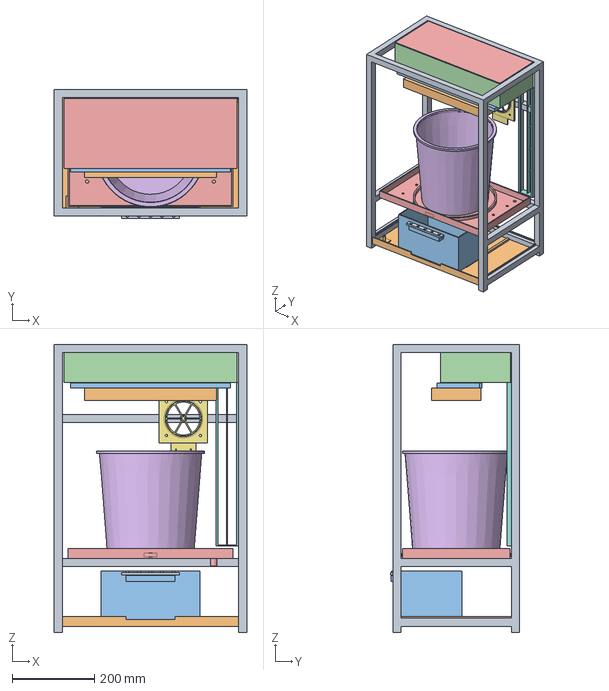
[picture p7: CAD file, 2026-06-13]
mechanical/cad/step/opencanopy-assembly.step
468.0 x 314.0 x 700.0 mm

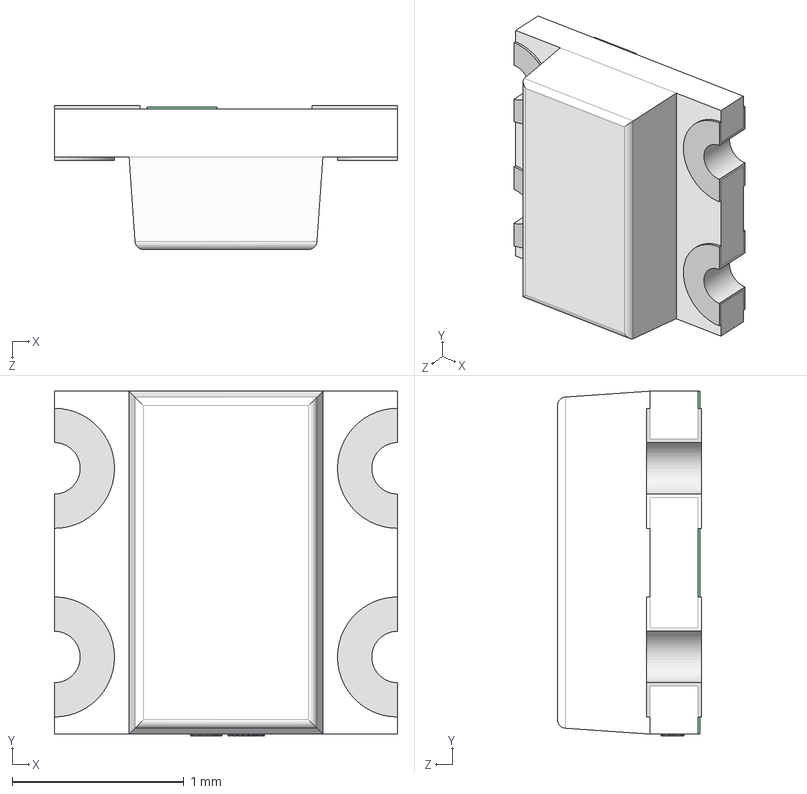
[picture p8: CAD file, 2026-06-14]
electronics/pcb/3d-models/WS2812B-2020_C965555.step
2.00 x 2.01 x 0.84 mm

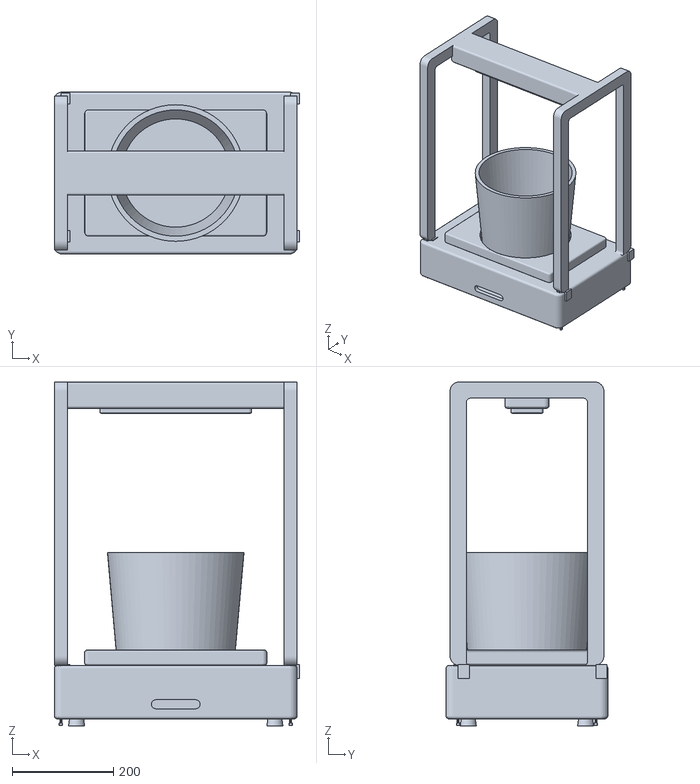
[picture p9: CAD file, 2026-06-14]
mechanical/cad/exports/opencanopy_v0.stl
485.0 x 319.9 x 680.0

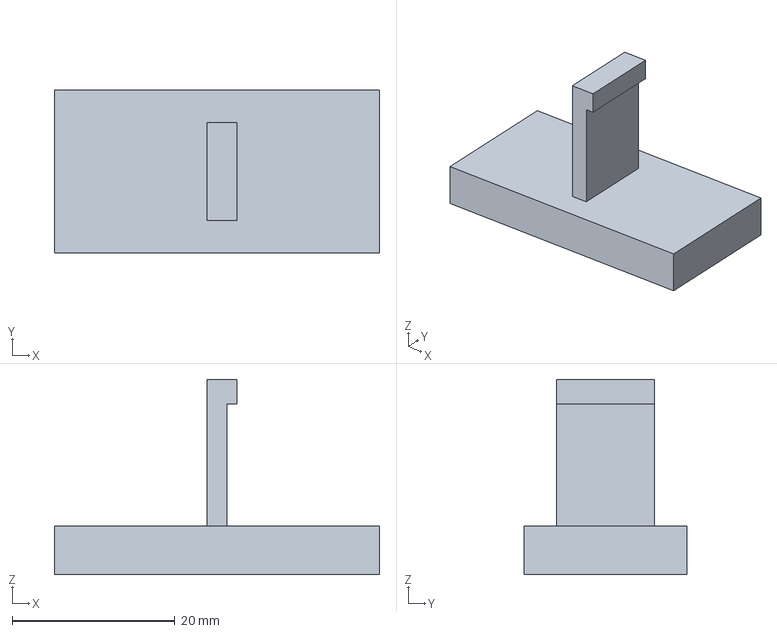
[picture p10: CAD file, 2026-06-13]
mechanical/cad/step/coupon-snap-fit.step
40.0 x 20.0 x 24.0 mm

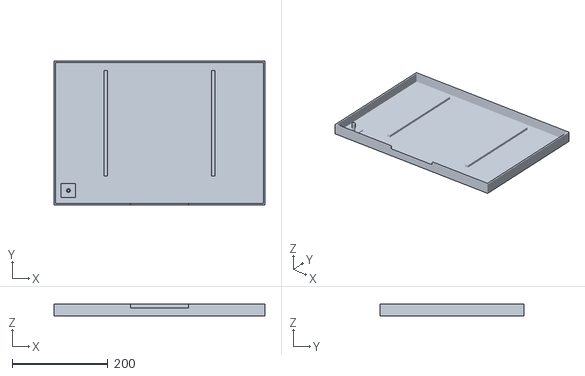
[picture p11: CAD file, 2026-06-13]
mechanical/stl/assembly/leak-tray.stl
440.0 x 300.0 x 24.0

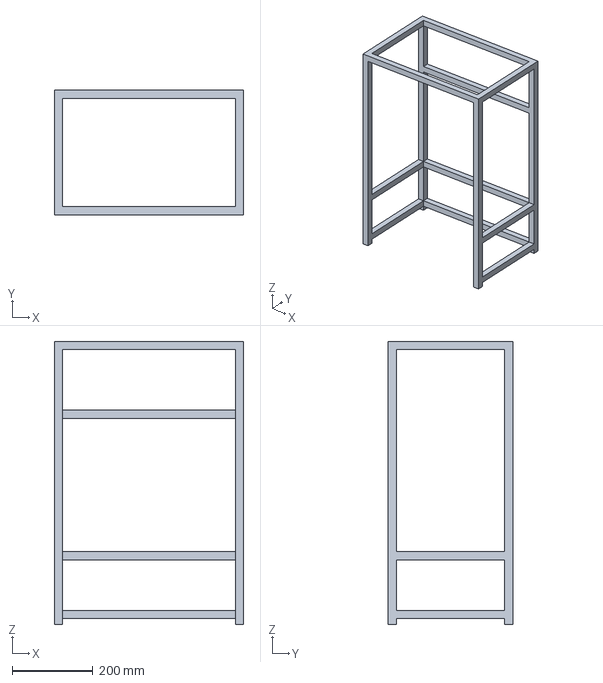
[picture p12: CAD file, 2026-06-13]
mechanical/cad/step/frame.step
468.0 x 308.0 x 700.0 mm

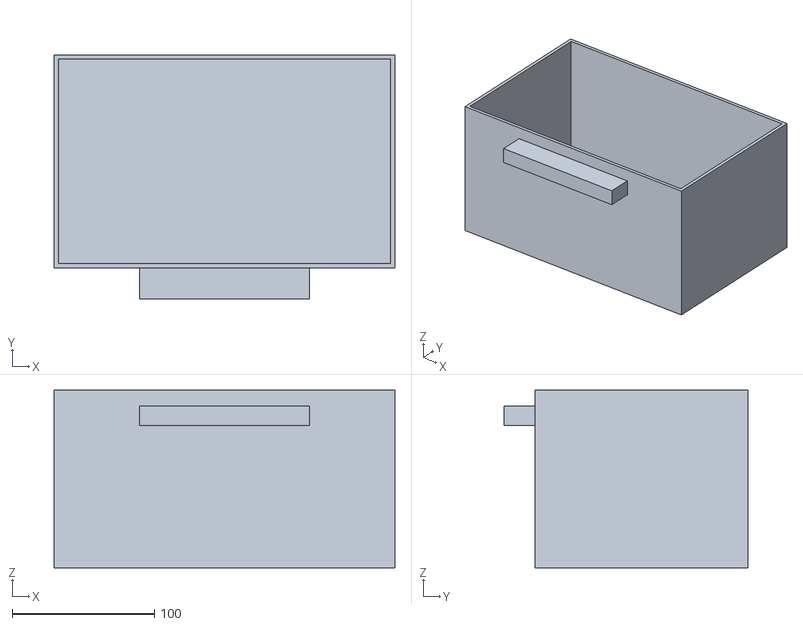
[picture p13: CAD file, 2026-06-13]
mechanical/stl/assembly/reservoir.stl
240.0 x 172.0 x 125.0

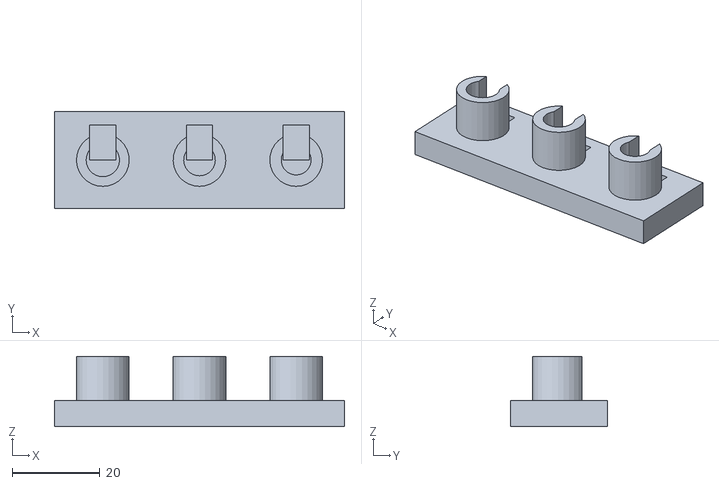
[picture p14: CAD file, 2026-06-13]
mechanical/stl/prototypes/coupon-tube-clip.stl
66.0 x 22.0 x 16.0

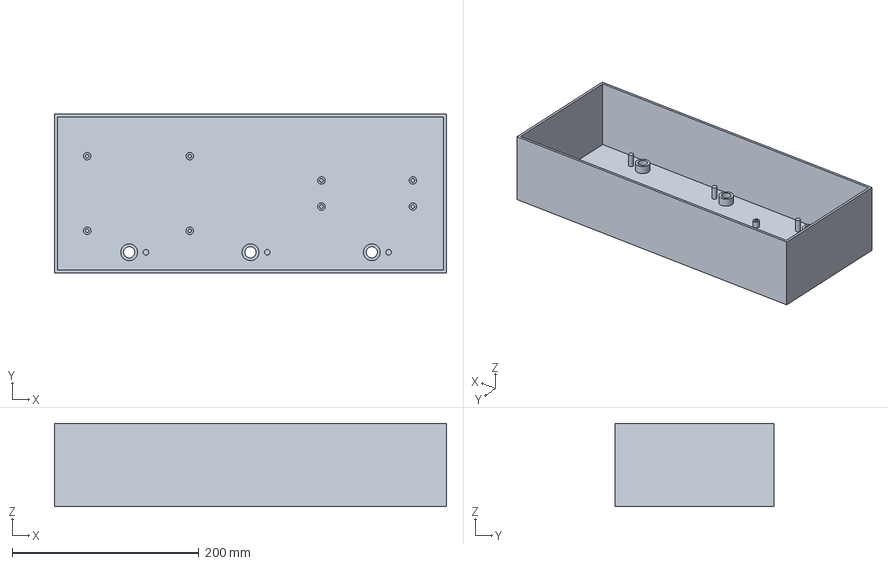
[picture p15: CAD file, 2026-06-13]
mechanical/cad/step/electronics-dry-bay.step
420.0 x 170.0 x 89.0 mm

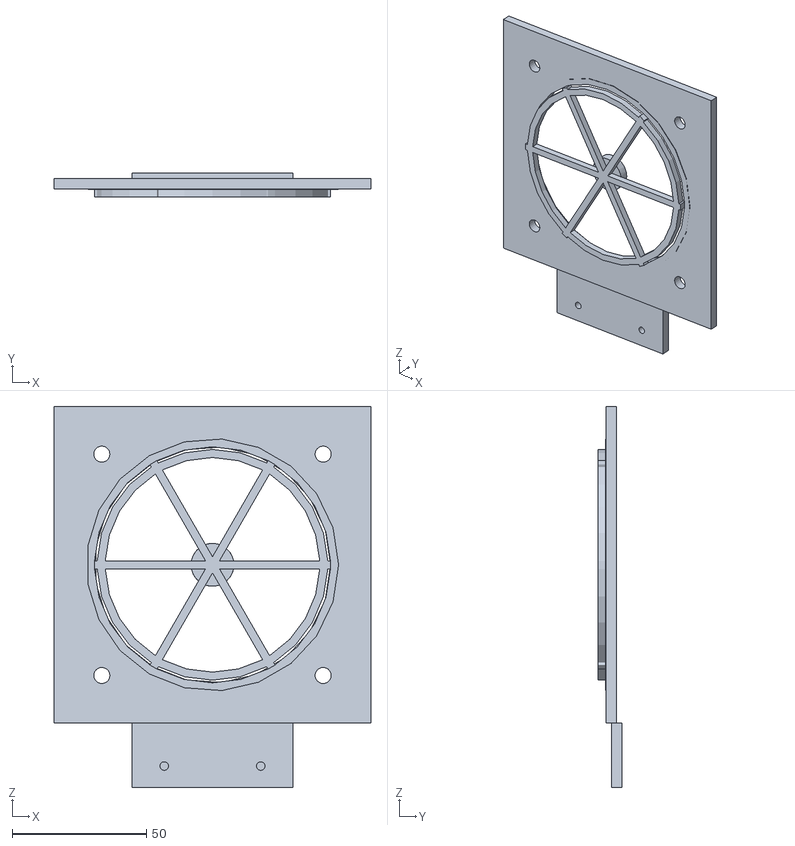
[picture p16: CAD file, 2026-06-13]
mechanical/stl/assembly/fan-mount.stl
118.0 x 9.00 x 142.0

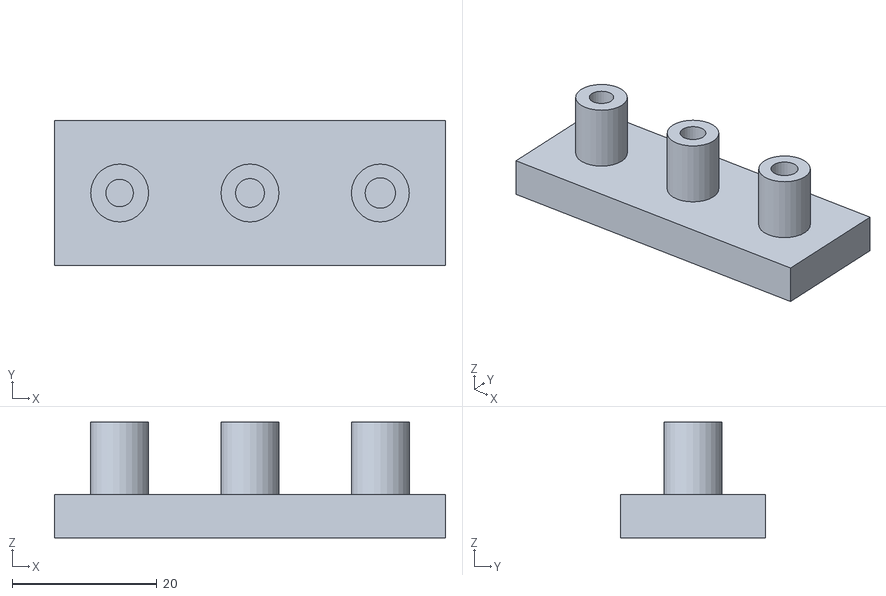
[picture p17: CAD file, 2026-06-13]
mechanical/stl/prototypes/coupon-heatset-insert.stl
54.0 x 20.0 x 16.0

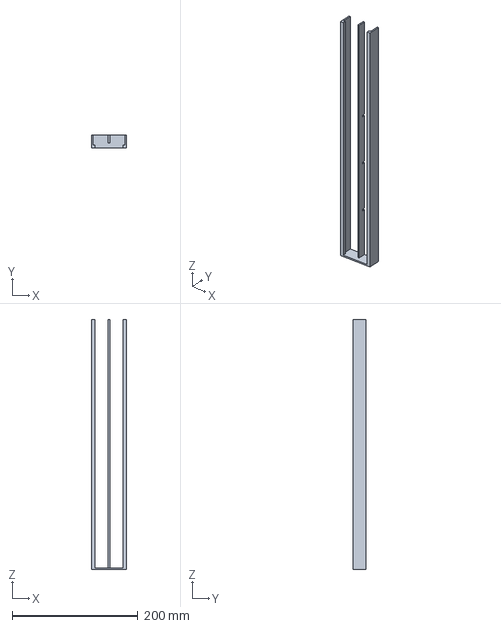
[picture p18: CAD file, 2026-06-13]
mechanical/cad/step/cable-channel.step
55.2 x 20.8 x 398.0 mm

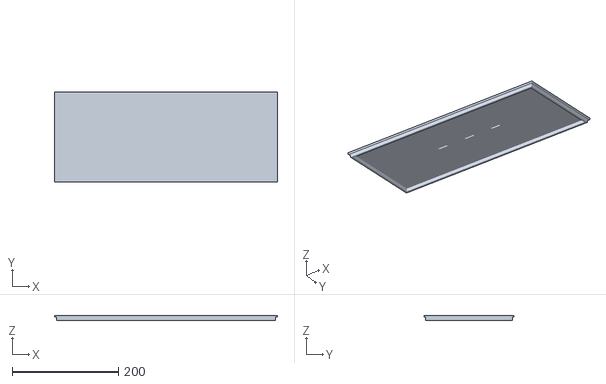
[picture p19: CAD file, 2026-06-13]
mechanical/stl/assembly/electronics-dry-bay-lid.stl
420.0 x 170.0 x 9.00

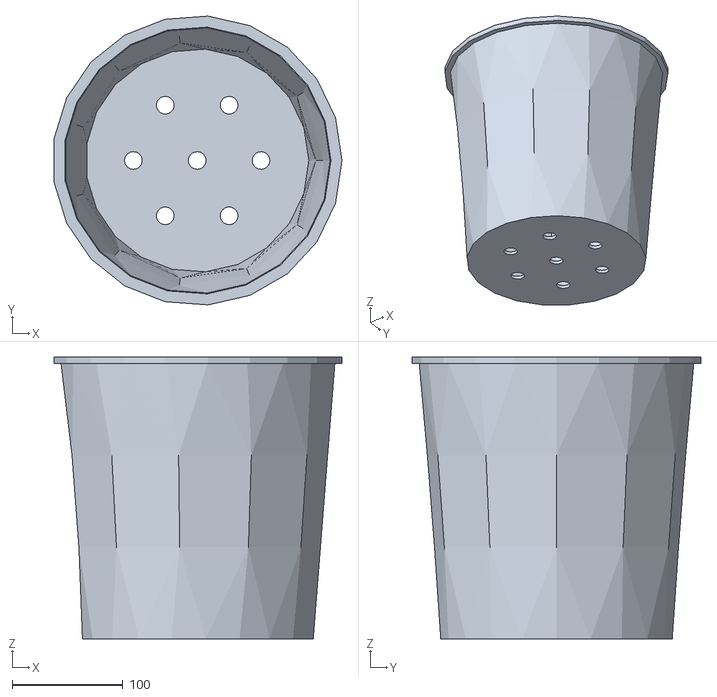
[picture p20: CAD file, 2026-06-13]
mechanical/stl/assembly/pot.stl
260.5 x 261.3 x 255.0

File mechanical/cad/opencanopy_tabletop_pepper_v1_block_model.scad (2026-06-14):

// OpenCanopy Tabletop Pepper — v1 product model (two-pillar Scandinavian architecture)
// SPDX-License-Identifier: CERN-OHL-S-2.0
//
// MAJOR REDESIGN (supersedes the arched-frame model). Architecture:
//   - one low integrated BASE (the product body): a 6 L passive self-watering reservoir +
//     an integrated grow well. The base is a SINGLE WET ZONE; there is NO electronics bay
//     in the base (electronics moved to the top — see below).
//   - TWO vertical wooden cylindrical PILLARS, centred on the base depth, rising from dry
//     structural bosses.
//   - one horizontal top LED BLOCK spanning the pillars; below it, ONE centered LED PANEL (8×6
//     emitters across one board, WI-PL-06) on a finned passive HEATSINK, single central mount.
//     The small 1.6 mm controller+driver PCB is ENCAPSULATED inside the block
//     (in an internal bay on standoff bosses), with a USB-C port through the rear face.
//   - a removable RAISED GROW INSERT (slotted/perforated, semi-hydro) for ONE pepper plant.
//   - passive self-watering: reservoir below + wicking. NO pump, NO fan, no screen/controls,
//     4 status LEDs only.
//
// Wet/dry separation is now TOP (electronics) vs BOTTOM (water) — not an in-base wall. Only
// sealed low-voltage sensor leads + status-LED light pipes touch the base, entering through a
// grommet at the right pillar; power (USB-C) enters at the TOP. Pillars and the grow module
// share Y (=160, base centre) so a THIN block puts the LED directly over the plant. The base
// stays low (135 mm) because the grow insert is a RAISED planter rising above the top.
//
// Per-part export:  openscad -D 'part="base"' --render -o base.stl this_file.scad
// Origin = front-left-bottom. X=width(0..480) Y=depth(0..320) Z=height(0..680). mm

// ----------------------------- parameters --------------------------------
env_w = 480; env_d = 320; env_h = 680;
$fn = 64;

// base (the product body — single wet zone)
foot_h  = 12;
base_h  = 135;                 // base top plane (visible base from foot top = 123 mm, <=130)
wall_t  = 12; floor_t = 10; top_t = 8;
base_rv = 16; base_re = 4;     // selective radii: vertical corners R16, top/bottom R4
floor_z = foot_h + floor_t;    // 22  inner floor
ceil_z  = base_h - top_t;      // 127 underside of base top

// grow module / LED optical center (centred on the base)
gm_x = 240; gm_y = 160;

// grow well opening (top of base) — rounded rectangle
well_w = 270; well_d = 190; well_r = 8;

// removable raised grow insert (semi-hydro basket)
ins_w = 244; ins_d = 180; ins_wall = 6; ins_r = 10;
ins_bot_z = 110;               // slotted bottom rests at the reservoir top (wick contact)
ins_top_z = 250;               // rises to 250 -> ~115 mm raised planter above base top

// passive reservoir (wet) — sits on the inner floor BETWEEN the two pillar bosses
res_x0 = 90; res_x1 = 390; res_y0 = 40; res_y1 = 290; res_z0 = floor_z; res_z1 = ins_bot_z - 0.5; // 0.5 mm wick gap

// wooden pillars (rise from dry structural bosses in the base; centred on base depth)
pil_d = 28; pil_r = 14; pil_x0 = 64; pil_x1 = env_w - 64; pil_y = gm_y;
boss_d = 42;                   // dry structural boss around each pillar foot
socket_d = 30;                 // pillar seats 30 mm into base and into block
pil_bot_z = base_h - socket_d; // 105
pil_top_z = env_h - 48 + socket_d;  // 30 mm up into the block (= 662)

// top LED block (mostly rectangular; only the pillar-hole ends are rounded)
blk_l = 440; blk_d = 60; blk_h = 48;
blk_z = env_h - blk_h;         // 632
blk_x0 = (env_w - blk_l)/2;    // 20
blk_y0 = gm_y - blk_d/2;       // 130
blk_end_r = 16;                // end-cap radius (around pillar holes)
blk_edge_r = 2;                // long edges

// grow LED PANEL + heatsink — ONE centered board (emitters spread across its face, 8×6 grid,
// per PL-06 fixture C) on a finned passive heatsink, single central mount under the block.
// Sized to fit between the pillar inner faces (≤ ~324 mm) — panel meets uniformity at the
// 150 mm target clearance, where a strip/bar needed ≥200–225 mm (WI-PL-06).
pan_w = 300; pan_d = 210; pan_t = 3;            // panel board (X × Y × thickness)
emit_z = 600;                                   // emitter plane (faces down); board = emit_z..+pan_t
emit_nx = 8; emit_ny = 6;                        // emitter grid across the panel face
hs_base = 6; hs_fin_h = 22; hs_fin_t = 3; hs_fin_pitch = 18;   // finned heatsink (on the board's back)

// encapsulated PCB bay inside the block right end (around the right pillar)
bay_x0 = 384; bay_x1 = 454; bay_z0 = 634; bay_z1 = 648;     // internal void (2 mm skin below)
pcb_x0 = 388; pcb_x1 = 450; pcb_t = 1.6; pcb_z = 638;        // 1.6 mm board on standoff bosses
pcb_my = [gm_y-16, gm_y+16]; pcb_mx = [394, 444];           // 4 mounting-hole / boss positions

// joints / hardware
m4 = 4.5; m4_head = 8; dowel_d = 4; setscrew = 4.5; m25 = 2.7;
pil_clear = 0.6;               // pillar-to-socket diametral clearance

// selective-radius box: vertical-corner radius rv, top/bottom edge radius re
module rcube(size, rv, re) {
    re = min(re, rv, size[2]/2 - 0.01); rv = max(rv, re);
    minkowski() {
        translate([re, re, re]) linear_extrude(max(0.2, size[2] - 2*re))
            offset(r=rv-re) offset(delta=-(rv-re))
                square([max(0.2,size[0]-2*re), max(0.2,size[1]-2*re)]);
        sphere(r=re, $fn=18);
    }
}
// horizontal pill on the front face (L along X, ht along Z, depth along Y), centred at x
module front_pill(L, ht, depth) { hull() for (x=[-L/2+ht/2, L/2-ht/2]) translate([x,0,0]) rotate([-90,0,0]) cylinder(h=depth, d=ht); }
// rounded-rectangle prism centred on (cx,cy), corner radius r, from z0 height h
module rrect(cx, cy, w, d, r, z0, h) { translate([cx,cy,z0]) linear_extrude(h) offset(r=r) offset(delta=-r) square([w,d], center=true); }

// ------------------------------- modules ----------------------------------
module feet() { for (x=[46, env_w-46], y=[46, env_d-46]) translate([x,y,0]) cylinder(h=foot_h, r1=17, r2=15); }

// BASE SHELL — low single-wet-zone body; cavity, grow well, two DRY pillar bosses, status
// slot, fill port, deck drain, underside pillar joints. All hardware in clearance holes.
module base_shell() {
    difference() {
        union() {
            difference() {
                translate([0,0,foot_h]) rcube([env_w, env_d, base_h-foot_h], base_rv, base_re);
                translate([wall_t, wall_t, floor_z]) cube([env_w-2*wall_t, env_d-2*wall_t, ceil_z-floor_z]); // wet cavity
                rrect(gm_x, gm_y, well_w, well_d, well_r, ceil_z-1, top_t+2);          // grow well opening
                translate([gm_x, 42, ceil_z-1]) cylinder(h=top_t+2, d=30);             // fill port (front apron)
                translate([gm_x, -1, 70]) front_pill(54, 9, wall_t+2);                 // status slot
                translate([gm_x, gm_y, ceil_z-1]) cylinder(h=top_t+2, d=20);           // deck drain (wet)
            }
            for (xc=[pil_x0, pil_x1]) translate([xc, pil_y, floor_z]) cylinder(h=base_h-floor_z, d=boss_d); // dry pillar bosses
        }
        for (xc=[pil_x0, pil_x1]) {
            translate([xc, pil_y, pil_bot_z]) cylinder(h=socket_d+2, d=pil_d+pil_clear);   // socket (from top)
            translate([xc, pil_y, -1]) cylinder(h=base_h+2, d=m4);                          // M4 shank from underside
            translate([xc, pil_y, -1]) cylinder(h=foot_h+4, d=m4_head);                     // underside counterbore
            translate([xc, pil_y+10, pil_bot_z-1]) cylinder(h=socket_d+3, d=dowel_d+0.4);   // anti-rotation dowel
        }
        translate([pil_x1, pil_y+boss_d/2-3, ceil_z-1]) cylinder(h=top_t+2, d=8);           // sealed sensor-lead grommet
    }
}

// WOODEN PILLAR — cylinder with tiny end chamfers; bottom into base socket (M4 insert pocket +
// dowel clearance), top into block. A rear flat keys the cable clip.
module pillar(xc) {
    translate([xc, pil_y, pil_bot_z]) difference() {
        union() {
            cylinder(h=pil_top_z-pil_bot_z, d=pil_d);
            cylinder(h=1.2, d1=pil_d-2, d2=pil_d);
            translate([0,0,pil_top_z-pil_bot_z-1.2]) cylinder(h=1.2, d1=pil_d, d2=pil_d-2);
        }
        translate([-pil_d/2, pil_d/2-1.5, base_h-pil_bot_z+8]) cube([pil_d, 2, pil_top_z-base_h-20]); // rear cable flat
        translate([0, 0, -1]) cylinder(h=26, d=6);                       // M4 insert pocket (bottom)
        translate([0, 10, -1]) cylinder(h=socket_d+1, d=dowel_d+0.4);    // anti-rotation dowel clearance
    }
}
module pillar_left()  { pillar(pil_x0); }
module pillar_right() { pillar(pil_x1); }
module pillars() { pillar_left(); pillar_right(); }
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

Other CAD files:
mechanical/stl/prototypes/coupon-snap-fit.stl
mechanical/stl/prototypes/coupon-reservoir-rail.stl
mechanical/cad/step/light-mount.step
mechanical/stl/assembly/pot-tray.stl
mechanical/cad/step/cable-clip.step
mechanical/cad/step/coupon-cable-channel-clip.step
mechanical/cad/step/coupon-diffuser-slot.step
mechanical/cad/step/coupon-heatset-insert.step
mechanical/cad/step/coupon-reservoir-rail.step
mechanical/cad/step/coupon-screw-boss.step
mechanical/cad/step/coupon-tube-clip.step
mechanical/cad/step/electronics-dry-bay-lid.step
mechanical/cad/step/fan-mount.step
mechanical/cad/step/leak-tray.step
mechanical/cad/step/led-fixture.step
mechanical/cad/step/pot-10L.step
mechanical/cad/step/pot-tray.step
mechanical/cad/step/pump-clip.step
mechanical/cad/step/reservoir-4L.step
mechanical/cad/step/sensor-clip.step
mechanical/cad/step/status-diffuser.step
mechanical/cad/step/tube-clip.step
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

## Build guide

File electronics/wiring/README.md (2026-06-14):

<!-- SPDX-License-Identifier: CERN-OHL-S-2.0 -->
# Wiring harness (WI-EE-05)

- [`harness-table.csv`](harness-table.csv) — every connector, pin, signal, polarity, voltage, wire
  gauge/colour, destination, and strain-relief callout (11 connectors, 32 pins). Every row carries
  polarity + voltage (spec §15.5 M4-03).
- [`wiring-diagram.svg`](wiring-diagram.svg) — full system wiring, drawn against the dry/wet zone
  model (§6.2).

## Strain-relief & drip-loop callouts (§8.5, §17.1)

Every removable wet-zone module gets a **drip loop** so water runs off the cable below the connector,
not into it: pump (`J_PUMP`), moisture probe (`J_MOIST`), reservoir level (`J_RES`), leak sensor
(`J_LEAK`). Each is also clamped/grommeted at the case wall or module so the wire cannot transmit
strain to the connector or PCB pad. Dry-zone runs (LED, SHT40, status board) get a service loop and a
clamp at the module end. *(No fan in V1 — [ECO-001](../analysis/ECO-001-fan-removal.md); the `J_FAN`
header is DNP and carries no harness.)*

## Labelling & routing rules

- Harness labels (`pump`, `LED`, `moisture`, `reservoir`, `leak`) match the mechanical cable
  channel in [WI-ME-07 cable/tube routing](../../plan/work-items/04-mechanical/WI-ME-07-cable-tube-routing.md)
  (§8.5).
- **DR-08 routing rule:** the pump **supply tube** must never cross over the electronics bay; the
  `J_PUMP` electrical run drip-loops below the electronics. This is called out on the diagram and is a
  hard constraint on the mechanical routing.

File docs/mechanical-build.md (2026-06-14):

# Mechanical build — v1 product model

Renders of the **OpenCanopy v1 product model** (480 × 320 × 680 mm) from the parametric
OpenSCAD source (`mechanical/cad/opencanopy_tabletop_pepper_v1_block_model.scad`),
rendered with VTK (`mechanical/cad/render_block.py`) and validated by an honest,
no-whitelist geometry audit (`mechanical/cad/audit.py`).

**Architecture (major redesign — two-pillar Scandinavian form):**

- One **low integrated base** (the product body, 135 mm) — a **single wet zone**: a passive
  **6 L reservoir** + an integrated **grow well**. There is **no electronics bay in the base**.
- **Two vertical wooden pillars** (Ø28) rising from dry structural bosses, **centred on the
  base depth**.
- One horizontal **top LED block** spanning the pillars; below it, **one centered LED grow
  panel + finned heatsink on a single central mount** (not a strip) — an 8×6 emitter board per
  **WI-PL-06** (fixture C: a panel meets uniformity at the 150 mm target clearance, where a strip
  needed ≥200–225 mm, which would force a taller unit). The LED optical centre is over the plant.
  The **small 1.6 mm controller + driver PCB is encapsulated inside the
  block** (internal bay on standoff bosses, 4 mounting holes), with a **USB-C port through the
  rear face** — no board exposed. The block prints in two parts (body + bottom lid).
- A **removable raised grow insert** (slotted/perforated, semi-hydro) for one pepper plant.
- **Passive self-watering** (reservoir + wicking). **No pump, no fan, no screen/controls;
  4 status LEDs only.**

**Wet/dry separation is now top (electronics) vs bottom (water)** — not an in-base wall. Only
sealed low-voltage sensor leads + status-LED light pipes touch the base (entering through a
grommet at the right pillar); power (USB-C) enters at the top. Pillars and the grow module
share Y (= 160, base centre) so a thin block places the LED directly over the plant with no
cantilever. The base stays low because the grow insert is a **raised planter** above the top.

## Interactive 3D model

**Drag to orbit, scroll to zoom.** The **full assembly — all parts** (web-standard glTF), rendered
**translucent** so the internals (reservoir, controller PCB, cabling, joints) are visible. Toggle
**Wireframe** below. Source: `mechanical/cad/exports/parts/*.stl` → `assets/models/opencanopy-v1.glb`
(`mechanical/cad/render_block.py::export_glb`); download the [GLB](assets/models/opencanopy-v1.glb).

<div style="margin:.4rem 0;display:flex;gap:1.2rem;align-items:center;flex-wrap:wrap;">
  <label style="display:inline-flex;align-items:center;gap:.4rem;"><input type="checkbox" id="oc-wire"> Wireframe</label>
  <label style="display:inline-flex;align-items:center;gap:.4rem;">Opacity <input type="range" id="oc-op" min="0.1" max="1" step="0.05" value="0.5"></label>
</div>

<script type="importmap">
{ "imports": {
  "three": "https://cdn.jsdelivr.net/npm/three@0.160.0/build/three.module.js",
  "three/addons/": "https://cdn.jsdelivr.net/npm/three@0.160.0/examples/jsm/"
}}
</script>
<script type="module">
import * as THREE from 'three';
import { OrbitControls } from 'three/addons/controls/OrbitControls.js';
import { GLTFLoader } from 'three/addons/loaders/GLTFLoader.js';

const el = document.getElementById('oc-viewer');
const scene = new THREE.Scene(); scene.background = new THREE.Color(0xf3f4f6);
const camera = new THREE.PerspectiveCamera(40, el.clientWidth/el.clientHeight, 1, 8000);
const renderer = new THREE.WebGLRenderer({ antialias: true });
renderer.setPixelRatio(window.devicePixelRatio); renderer.setSize(el.clientWidth, el.clientHeight);
el.appendChild(renderer.domElement);
scene.add(new THREE.HemisphereLight(0xffffff, 0x707070, 1.15));
const key = new THREE.DirectionalLight(0xffffff, 1.4); key.position.set(1, 2, 1.5); scene.add(key);
const controls = new OrbitControls(camera, renderer.domElement); controls.enableDamping = true;

const mats = [];
const setOpacity = v => mats.forEach(m => { m.opacity = v; m.transparent = v < 1; m.depthWrite = v >= 1; m.needsUpdate = true; });
new GLTFLoader().load('assets/models/opencanopy-v1.glb', (gltf) => {
  gltf.scene.traverse(o => { if (o.isMesh) { o.material.side = THREE.DoubleSide; mats.push(o.material); } });
  scene.add(gltf.scene);
  setOpacity(0.5);
  const box = new THREE.Box3().setFromObject(gltf.scene), size = box.getSize(new THREE.Vector3()), c = box.getCenter(new THREE.Vector3());
  const d = Math.max(size.x, size.y, size.z);
  controls.target.copy(c); camera.position.set(c.x + d*0.85, c.y + d*0.55, c.z + d*1.4);
  camera.near = d/200; camera.far = d*12; camera.updateProjectionMatrix();
}, undefined, (err) => { el.innerHTML = '<p style="padding:1rem">3D viewer failed to load — <a href="assets/models/opencanopy-v1.glb">download the GLB</a>.</p>'; });

document.getElementById('oc-wire').addEventListener('change', e => mats.forEach(m => { m.wireframe = e.target.checked; }));
document.getElementById('oc-op').addEventListener('input', e => setOpacity(parseFloat(e.target.value)));
new ResizeObserver(() => { if (!el.clientWidth) return; camera.aspect = el.clientWidth/el.clientHeight; camera.updateProjectionMatrix(); renderer.setSize(el.clientWidth, el.clientHeight); }).observe(el);
(function loop(){ requestAnimationFrame(loop); controls.update(); renderer.render(scene, camera); })();
</script>

## Product views

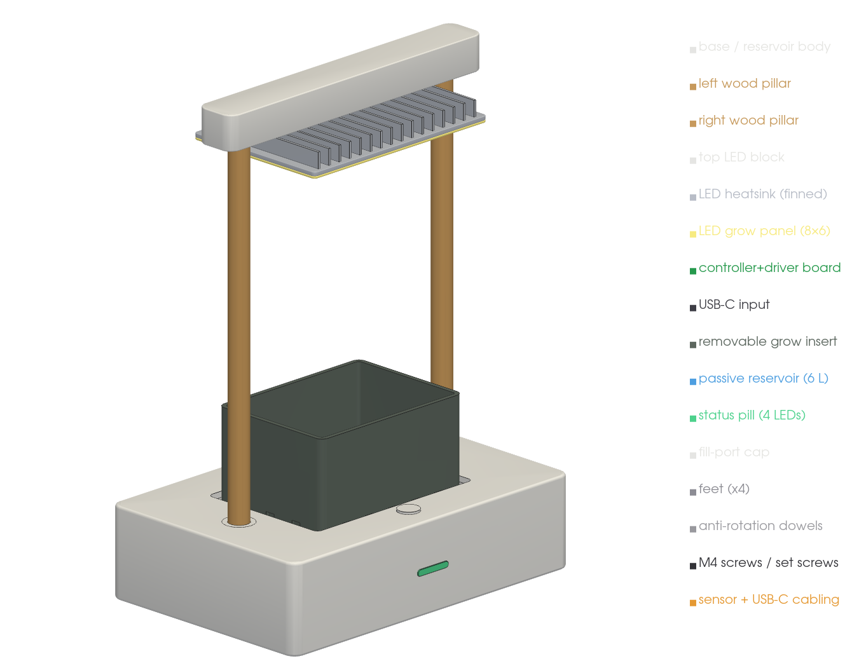
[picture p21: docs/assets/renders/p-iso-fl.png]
Front-left isometric


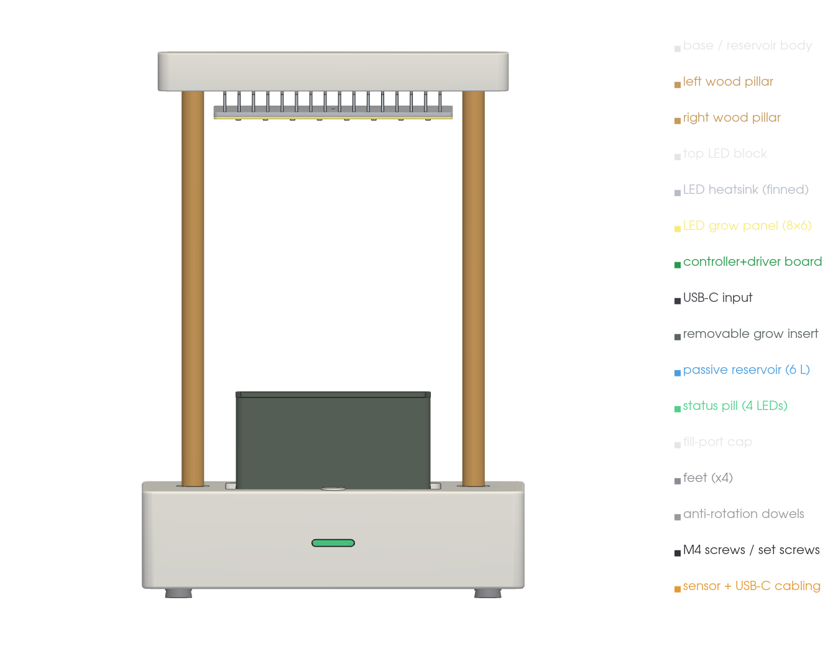
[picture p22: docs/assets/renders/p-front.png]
Front
 ·
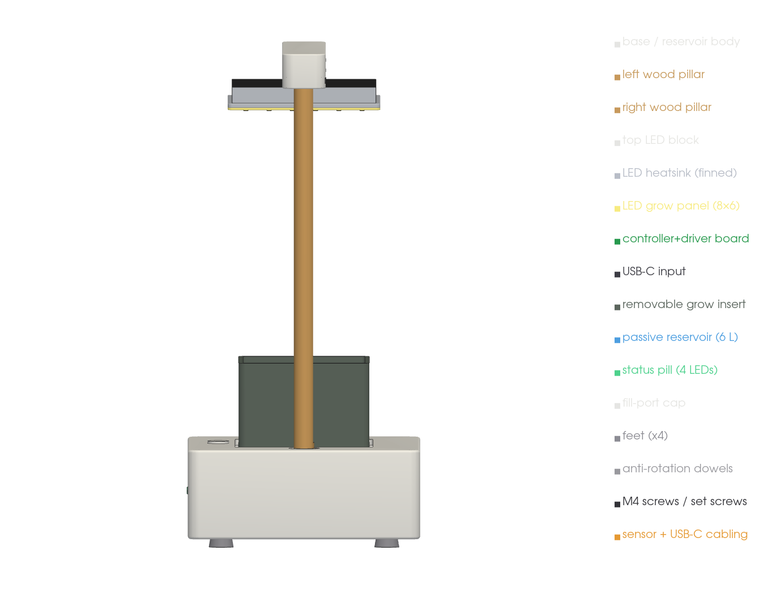
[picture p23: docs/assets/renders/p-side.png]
Side
 ·
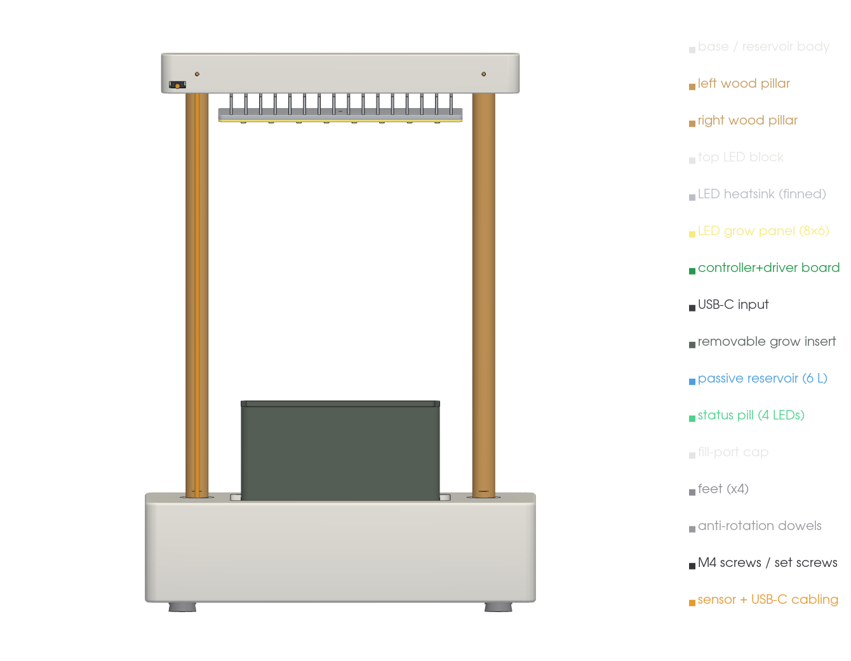
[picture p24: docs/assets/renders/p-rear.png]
Rear


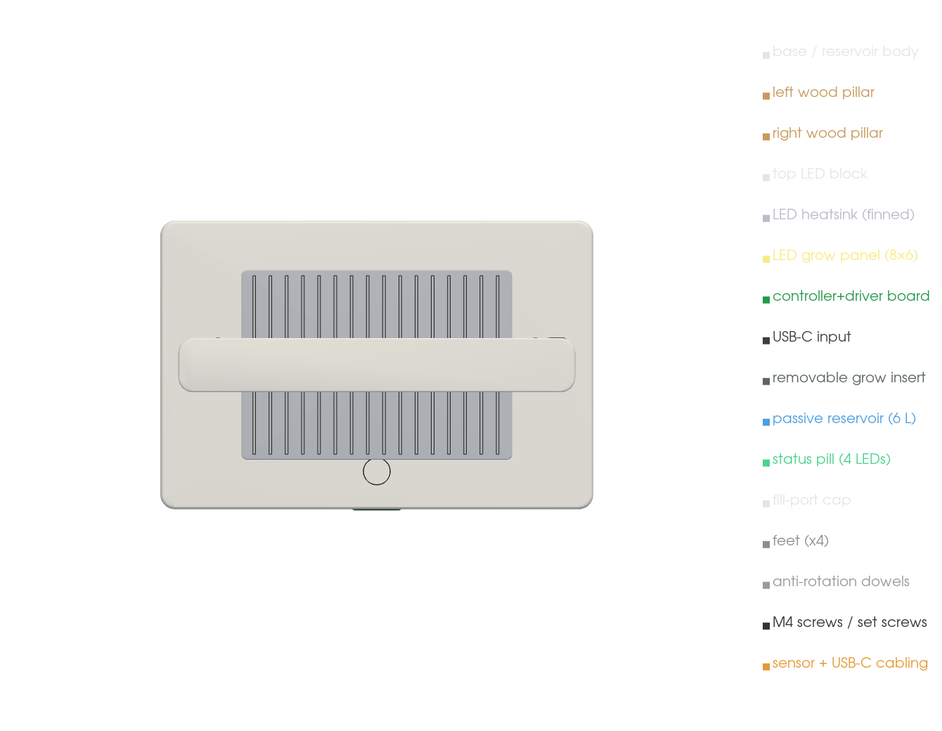
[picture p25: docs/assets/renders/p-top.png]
Top
 ·
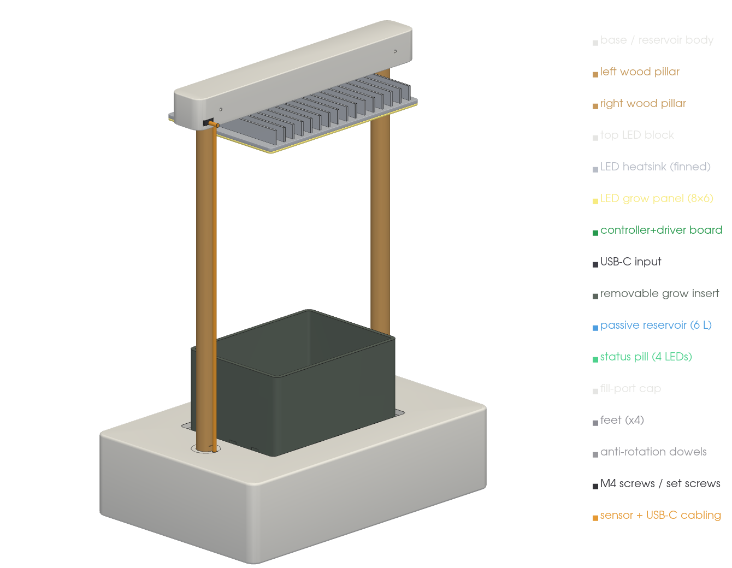
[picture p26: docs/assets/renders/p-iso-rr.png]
Rear-right isometric


## Validation (debug colours)

**LED centering** — the LED optical centreline and the grow module are both at X = 240,
Y = 160; the script confirms numerically `LED<->grow offset dX=0.0 dY=0.0` (acceptance ≤ 5 mm).

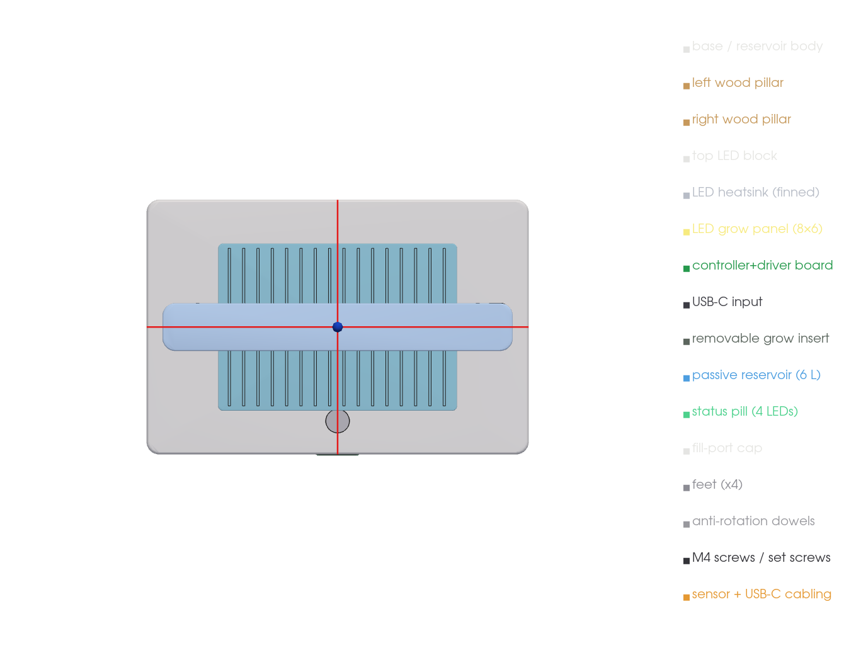
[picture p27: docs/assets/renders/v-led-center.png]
LED centering (top)


**Exploded assembly** · **underside (pillar screw access)** · **base service cutaway**
(reservoir + raised insert + wick path) · **cable cross-section** (sensor leads up the rear of
the right pillar to the top board):

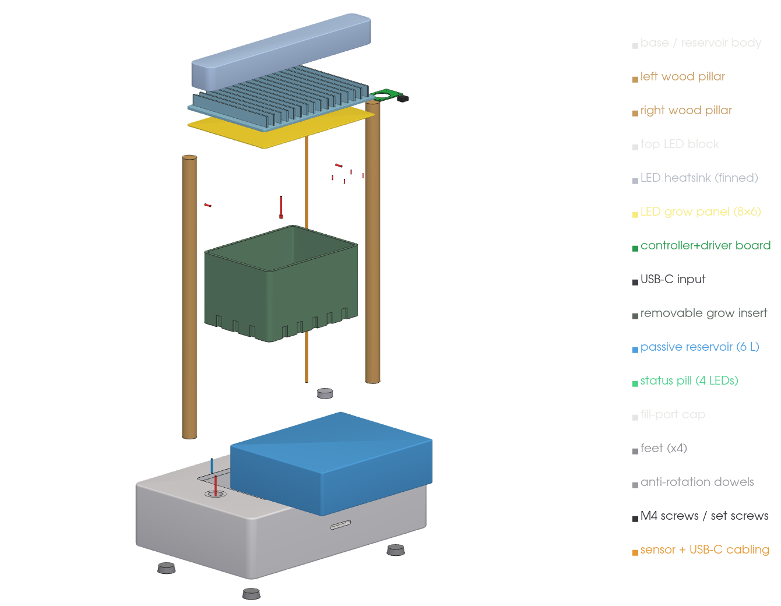
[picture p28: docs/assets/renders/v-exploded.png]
Exploded


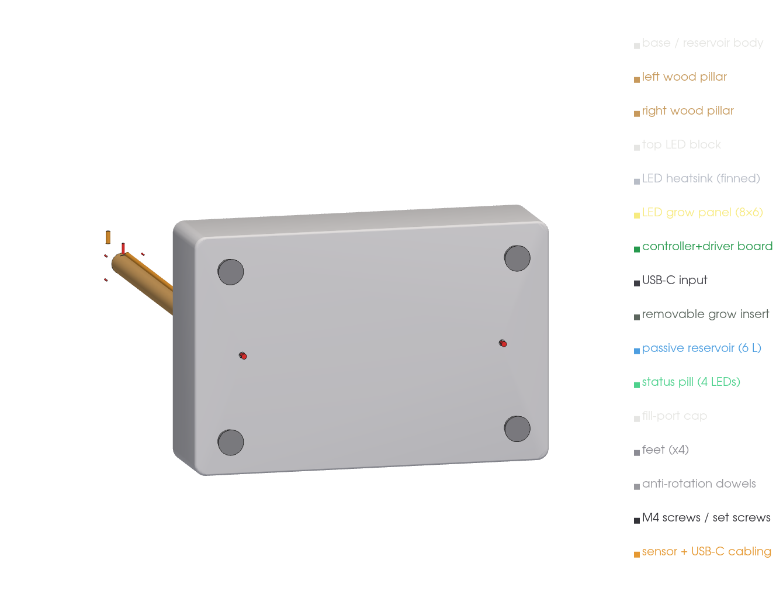
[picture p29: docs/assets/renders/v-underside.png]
Underside
 ·
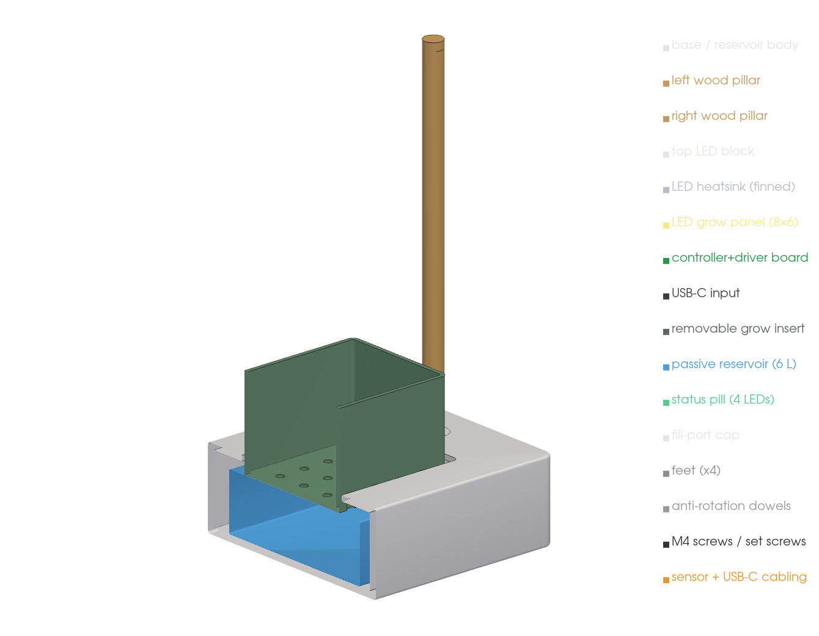
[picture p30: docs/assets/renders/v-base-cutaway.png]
Base cutaway
 ·
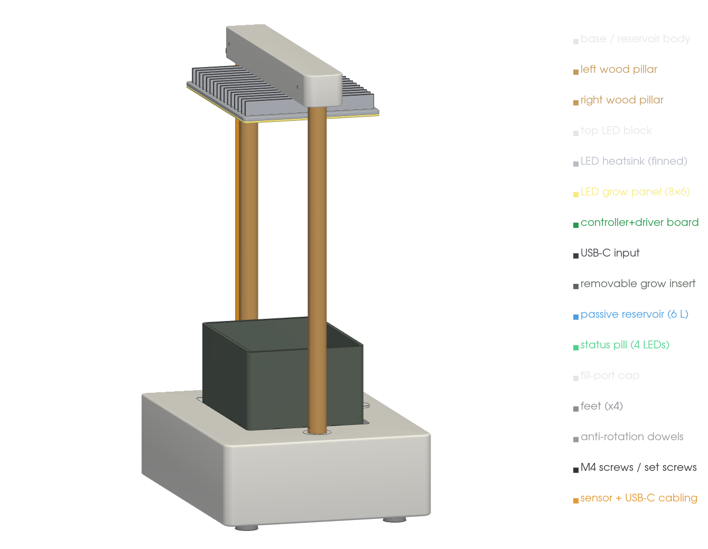
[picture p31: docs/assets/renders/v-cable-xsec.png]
Cable cross-section


## Checks

- **Geometry audit (`audit.py`) — CLEAN.** Honest interference check on the real meshes with
  **no whitelist**: it measures the true boolean **overlap volume** of every part pair (so
  abutting/touching faces are *not* mistaken for interpenetration) and each part's
  **nearest-neighbour gap** (so a floating/unsupported part is caught). Result: **no
  interpenetration > 80 mm³ and no floating parts.** Hardware sits in real clearance holes; the
  reservoir and raised insert are seated with a 0.5 mm wick gap; the controller PCB + USB-C are
  encapsulated in the block bay; the panel + heatsink hang on the central mount; the status pill +
  status LEDs sit in the front slot.
- **Grow light: one centered panel + finned heatsink, single central mount** (not a strip) — 8×6
  emitters across one board (WI-PL-06 fixture C), sized to fit between the pillar inner faces.
  Per PL-06 a panel meets uniformity (≥ 0.6) at the 150 mm target clearance, where a single bar
  needed ≥ 200–225 mm (a taller unit) — the panel keeps the form short and centered.
- **Status LEDs** — the 4 indicators use the electrical team's **WS2812B-2020** part (vendor model
  `electronics/pcb/3d-models/WS2812B-2020_C965555.step`), integrated at true datasheet dimensions
  (2.0 × 2.0 × 0.8 mm) behind the diffuser (see `mechanical/cad/vendor/README.md`).
- **LED centred over the grow module** — optical centre offset **0.0 / 0.0 mm** (≤ 5 mm limit).
- **Reservoir** — **6.6 L** gross (≥ 6 L usable target). The grow insert is a **raised planter**
  so the base stays low (≤ 130 mm visible); media capacity is a documented trade-off (see
  [ECO-003](ECO-003-v1-redesign.md) / open questions) pending a grow trial.
- **Joints:** each pillar seats 30 mm into a base socket with an **M4 from the underside** into a
  threaded insert + an **anti-rotation dowel**; the block sockets onto the pillar tops with a
  **rear set screw**. See [fastening & assembly](fastening.md).
- **Physics sim:** deferred for the two-pillar architecture (per maintainer) — geometry is
  validated by `audit.py`; a free-standing load sim can be re-run later (`physics_sim.py`).

Reproduce:

```sh
.venv-cad/bin/python mechanical/cad/render_block.py   # export parts + renders
.venv-cad/bin/python mechanical/cad/audit.py          # interference (volume) + float audit
openscad -D 'part="base"' --render -o base.stl mechanical/cad/opencanopy_tabletop_pepper_v1_block_model.scad
```

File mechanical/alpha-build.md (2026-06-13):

# Alpha build notes (spec §15.6 M5-09; WI-ME-08)

The first full unit assembled from the released source. This document is the
**assembly procedure + build log**; photos go in `validation/photos/` (Validation
track) and are linked here once the physical build is made.

> **Status:** Design complete and buildable on paper — all parts modelled,
> exported, manifold-clean (CI `stl_check`), and the assembly fits the locked
> envelope with verified clearances (`cad-verification-checklist.md`). The
> **physical alpha print/build is PENDING** and is performed jointly with the
> Validation track (it feeds WI-QA-01/02/03/04). Tick the photo/log boxes during
> that build.

## Bill of parts

- Printed parts: `stl/printable/*.stl` (see `print-settings.md` for material/zone).
- Bought parts: `bom-mechanical.csv` (pot, reservoir, extrusion, fasteners, fan,
  grommets, tubing, feet) + the LED head from the Light track + the PCB/harness
  from Electronics (WI-EE-04/05).

## Assembly order (bottom-up — water lives low, electronics high)

1. **Frame.** Cut and join the 20×20 uprights with top/mid/low rails. Fit the
   four levelling feet. Verify square and that it is stable with a full reservoir
   and a loaded pot (CG ≈ 305 mm, 44 % of height — bottom-heavy).
2. **Wet bay.** Drop in the `leak-tray`; seat the leak sensor in the sump boss.
   Slide the reservoir onto the cradle rails (drawer pulls out the front).
3. **Pump.** Clip the pump into the `pump-clip` on its silicone pad inside the
   reservoir; fit the intake filter; route 8 mm tube up the channel's tube pocket.
4. **Pot deck.** Fit the `pot-tray` on the mid rail; confirm the downspout drops
   into the leak tray. Seat the 10 L pot on the locating ring.
5. **Routing.** Mount the `cable-channel` to the rear-right upright. Run wiring in
   the wire pocket (separate from the tube). Fit grommets + form a **drip loop**
   below each dry-bay entry. Clip the moisture probe with `sensor-clip`.
6. **Fan.** Bolt the `fan-mount` to the rear with rubber grommets (no metal-to-frame
   contact); fit the guard side toward the canopy.
7. **Light.** Fix the `light-mount` carrier to the upright hole-row at the height
   giving 150–300 mm canopy clearance; attach the LED head; **fit the secondary
   retention tether** through both eyelets.
8. **Electronics.** Mount the controller PCB and remote LED driver on the dry-bay
   heat-set bosses; land the labelled harness through the grommets; close the lid.
9. **Power-on dry check** before any water (hand off to WI-QA-01).

## Build log

- [ ] All printed parts printed in the materials from `print-settings.md`.
- [ ] Coupons printed and `fit-tests.md` filled; `params.py` clearances calibrated.
- [ ] Frame assembled, square, stable with full load.
- [ ] Reservoir + pot insert/remove tested tool-free (no wires disturbed).
- [ ] Drip loops formed at every electronics entry; harness labels match
      `electronics/wiring/harness-table.csv`.
- [ ] Secondary retention on the light verified (fixture cannot fall).
- [ ] Photos captured to `validation/photos/alpha-build/` and linked here.
- [ ] Assembly feasibility confirmed → M5-09 acceptance.

## Notes / deviations

_Record any fit issues, part substitutions, or `params.py` changes here. Any change
to a locked envelope value requires a risk-register entry (scope-lock contract)._

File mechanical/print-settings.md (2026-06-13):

# Print settings (spec §8.3, §12.2, §16.2)

Recommended material and slicer settings for the OpenCanopy printed parts. Material
choice follows the §8.3 zone rules: **no PLA** anywhere near LED heat or persistent
humidity.

## Material by part

| Part (STL) | Zone | Material | Why |
|---|---|---|---|
| `leak-tray`, `pot-tray`, `pump-clip` | wet | **PETG** | Food-/water-adjacent, tough, hydrolysis-OK |
| `reservoir` (if printed, else bought) | wet | **PETG** (food-safe) | Hand-cleanable, no PLA in humidity |
| `electronics-dry-bay`, `-lid` | dry/upper | **PETG** or **ASA** | Splash protection, dimensional stability |
| `cable-channel`, `cable-clip`, `tube-clip`, `sensor-clip` | mixed | **PETG** | Toughness, repeated flexing |
| `light-mount` | LED-adjacent | **ASA** or **ABS** (or heat-proven PETG) | Sits near the driver/LED heat (§8.3) |
| `fan-mount` | grow | **PETG** or **ASA** | Vibration, mild warmth |
| `status-diffuser` | front trim | **frosted PETG / acrylic** | Translucent light pipe (§3.4) |
| decorative trim | dry/front | wood / bamboo / wood-fill PLA **only away from heat & moisture** | Aesthetic (§3.4) |

Fasteners near water: **stainless steel** (§16.2). Heat-set inserts: **M3 brass**.

## Slicer baseline (0.4 mm nozzle)

| Setting | Value | Notes |
|---|---|---|
| Layer height | 0.20 mm | 0.28 mm OK for `leak-tray`/`frame brackets` |
| Walls / perimeters | 3 (≥1.2 mm) | 4 for `light-mount`, `fan-mount` (load/heat) |
| Top/bottom layers | 5 | watertightness for trays |
| Infill | 30 % gyroid | 40–50 % for load-bearing mounts |
| PETG temp | 235–245 °C / bed 75–85 °C | per filament |
| ASA/ABS temp | 240–260 °C / bed 95–110 °C, enclosure | manage warping |
| Cooling | PETG 30–50 %, ASA/ABS low/off | |
| Seam | rear / hidden faces | |

## Orientation & supports

- **Trays (`leak-tray`, `pot-tray`):** print open-side up; no supports; brim for ASA.
- **`light-mount`:** arms flat on the bed; the eyelets and bosses print without supports.
- **`fan-mount`:** guard side up; the guard rings + spokes bridge cleanly at 0.2 mm.
- **`cable-channel`:** print standing or laid on its back; the open mouth needs no support.
- **`electronics-dry-bay`:** floor down; the grommet collars and standoffs print upright.
- **Coupons:** flat as exported; print the whole set first (see `fit-tests.md`).

## Dimensional fits (validated by coupons → `fit-tests.md`)

| Fit | Param | Nominal |
|---|---|---|
| Snap-fit interference | `CLEAR_SNAP` | 0.20 mm |
| Sliding rail (reservoir) | `CLEAR_SLIDE` | 0.30 mm |
| Press / heat-set bore | `CLEAR_PRESS` / `HEATSET_M3_DIA` | 0.10 mm / 4.0 mm |
| Tube clip grip (8 mm OD) | `TUBE_CLIP_GAP` | 0.4 mm |

> All clearances live in `cad/source/opencanopy/params.py`. After running the
> coupons, set the values that fit **your** printer/material there and re-run
> `build.py` so every part inherits the calibrated fit.

## 40 °C survival (§12.2 acceptance)

Parts near the LED/driver and in the warm bay must not deform at 40 °C. PETG (Tg
≈ 80 °C) and ASA/ABS clear this comfortably; PLA (Tg ≈ 60 °C, creeps far lower
under load) does **not** and is excluded from heat/humidity zones. The coupon set is
heat-soaked at 40 °C for 4 h as the gate (see `fit-tests.md`).

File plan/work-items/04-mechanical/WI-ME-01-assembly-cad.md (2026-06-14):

# WI-ME-01 — Full assembly CAD

| Field | Value |
|---|---|
| Track | Mechanical |
| Milestone | M5-01 |
| Depends on | WI-PS-04 |
| Spec refs | §8.1, §8.2, §3.3, §3.4, §12.1 |
| Status | Done — **re-scoped by [ECO-003](../../../docs/ECO-003-v1-redesign.md)** |

> **🔄 Re-scoped by [ECO-003](../../../docs/ECO-003-v1-redesign.md):** the assembly is now a
> **two-pillar** form — base + two wooden pillars + top LED block + removable raised grow insert —
> with **electronics in the top block** and **passive watering**; wet/dry separation is **top vs
> bottom**. The authoritative model is now the OpenSCAD
> `mechanical/cad/opencanopy_tabletop_pepper_v1_block_model.scad` (geometry audit CLEAN; LED centred
> over the plant, offset 0.0/0.0). The build123d source + STEP below are the superseded arched-frame
> model, retained for history.

## Objective

Model the complete **two-pillar** assembly (base + two pillars + top LED block + raised grow insert)
within the locked compact envelope, with the LED centred over the plant and **top/bottom** wet/dry
separation.

## Deliverables

- [x] Source CAD + STEP for the full assembly (`mechanical/cad/source/` parametric build123d
      model; `mechanical/cad/step/opencanopy-assembly.step`).
- [x] Open-frame vertical stack: upper dry bay, LED zone, grow zone, lower pot, bottom wet bay (§8.1).
- [x] Within locked envelope 480 × 320 × 700 mm (assembly bbox 468 × 314 × 700, asserted on every
      build); open front, hidden wiring, translucent status diffuser per §3.4.
- [x] CAD verification checklist (§12.1): see `mechanical/cad-verification-checklist.md`, with numbers
      computed by `verify.py` (insert/remove paths, clearances, CG 305 mm/44 % H with full reservoir +
      plant, drip/leak path) — all PASS.

## Acceptance criteria

- All modules placed (spec §15.6 M5-01); envelope within §3.3 compact target. ✅
- "Water fails downward; electronics live upward" rule (§6.2) visibly satisfied. ✅
  (`assembly.assert_zone_separation()` proves no dry part dips below the pot deck.)

## Notes

Authoritative source is the parametric build123d model (plain-text, regenerates STEP/STL/SVG
deterministically). Drawings in `mechanical/drawings/`. Toolchain + regen in
`mechanical/cad/source/README.md`.

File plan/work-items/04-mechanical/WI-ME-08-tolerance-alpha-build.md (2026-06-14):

# WI-ME-08 — Print tolerances & alpha build

| Field | Value |
|---|---|
| Track | Mechanical |
| Milestone | M5-08, M5-09 |
| Depends on | WI-ME-02, WI-ME-04, WI-ME-05, WI-ME-07 (WI-ME-03/06 superseded — ECO-003/ECO-001) |
| Spec refs | §8.3, §12.2, §14.1 (mechanical/) |
| Status | In progress — **re-scoped by [ECO-003](../../../docs/ECO-003-v1-redesign.md)** |

> **🔄 Re-scoped by [ECO-003](../../../docs/ECO-003-v1-redesign.md):** the alpha build is now the
> **two-pillar** unit. The authoritative geometry check is the OpenSCAD **`audit.py`** (no-whitelist,
> volume-based interference + float — **CLEAN**), which **replaces** the old `collision_check.py`/FCL
> step below. Add coupons for the **pillar↔base socket**, the **PCB standoff/M2.5 bosses**, and the
> **block body↔lid seam**. The build123d coupon set + STLs below are the superseded arched model.

## Objective

Validate print tolerances with coupons (incl. pillar socket, PCB standoffs, block body/lid seam),
then build and document the first full **two-pillar** alpha unit.

## Deliverables

- [x] Tolerance coupons (§12.2): all seven — snap-fit, screw boss, heat-set insert, tube clip, diffuser
      slot, cable-channel clip, reservoir rail/slide — in `mechanical/stl/prototypes/` (graded fits).
- [x] `mechanical/print-settings.md` (material-by-zone + slicer baseline) + `mechanical/fit-tests.md`
      (coupon matrix; results table awaiting the physical print run).
- [x] Released STLs in `mechanical/stl/printable/`; material choices per §8.3 documented in
      `print-settings.md` (PETG/ASA/ABS, **no PLA** near heat/humidity).
- [x] Alpha build assembly procedure + log in `mechanical/alpha-build.md`.
- [ ] **Physical alpha build: photos** (`validation/photos/alpha-build/`) — PENDING a print/build.

## Acceptance criteria

- **Fit risk retired by simulation.** `cad/source/collision_check.py` runs the real models through
  **FCL** (python-fcl) with a configurable worst-case error margin: zero interferences, every clearance
  ≥2 mm, surviving a 1.0 mm typical-FDM closure budget (and a 1.6 mm harsh band). It also caught + fixed
  8 real interferences in the first model. See `mechanical/tolerance-analysis.md`. The coupons are now a
  one-print **process-band confirmation**, not a fit discovery.
- Coupons pass §12.2 acceptance (no cracking, no excessive force, survive 40 °C). ⏳ Dimensional fits
  validated by sim; snap-fit strain within PETG allowable (1.4 %); 40 °C warp covered by material
  selection (PETG/ASA Tg ≫ 40 °C). Remaining physical confirmation runs during the alpha build (with
  the Validation track).
- Assembly feasible (spec §15.6 M5-09). ⏳ Design demonstrates feasibility (envelope + clearances +
  tool-free service all verified in `cad-verification-checklist.md`; assembly order in `alpha-build.md`);
  physical confirmation pending the build.

## Notes

This item spans M5-08 (coupons — design **done**) and M5-09 (alpha print/build — **pending hardware**).
Everything that can be produced without a printer is complete; the remaining checkboxes require an
actual print run and are executed with the Validation track (feeds WI-QA-01/02/03/04). Once printed,
record clearances in `fit-tests.md`, calibrate `params.py`, and flip this to Done.

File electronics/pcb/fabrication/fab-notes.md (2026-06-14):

<!-- SPDX-License-Identifier: CERN-OHL-S-2.0 -->
# WI-EE-07 — Fabrication package

**Status:** BOM (`bom.csv` + `alternates.csv`) complete and **passing `scripts/bom_check.py`** (incl.
`--strict`); fab notes + stackup specified. A **headless programmatic draft** fab package (Gerbers +
drill + PnP + BOM) is generated from the netlist by the tscircuit flow ([ECO-002](../../analysis/ECO-002-pcb-toolchain.md);
KiCad retired). A **fab-ready** package needs real footprints + a reviewed layout (see
[`programmatic/README.md`](../programmatic/README.md)).
**Spec refs:** §14.1, §16.1, §16.3.

## 1. What's in the package

| Artifact | Path | State |
|---|---|---|
| BOM | [`bom/bom.csv`](../../bom/bom.csv) | ✔ complete, passes §16.3 check |
| Alternates | [`bom/alternates.csv`](../../bom/alternates.csv) | ✔ complete |
| Fab notes / stackup | this file | ✔ |
| Gerbers + drill + PnP + BOM | [`pcb/programmatic/out/controller.gerbers.zip`](../programmatic/out/controller.gerbers.zip) | ◑ **draft** (placeholder IC/connector footprints; autorouter-grade) |
| Board as KiCad PCB | [`pcb/programmatic/out/controller.kicad_pcb`](../programmatic/out/controller.kicad_pcb) | ◑ draft (optional interchange) |

The draft package is produced by [`pcb/programmatic/build.sh`](../programmatic/build.sh) (a single
script step). It is real fab-FORMAT data but not fab-ready — see §3.

## 2. Fabrication spec (controller PCB, PCB1)

| Parameter | Value |
|---|---|
| Layers | 4 (signal / GND / power / signal) — [stackup](../../analysis/WI-EE-04-pcb-layout.md#1-stackup) |
| Copper | 1 oz outer (high-current paths as filled pours, [WI-EE-06](../../test/pcb-verification.md)) |
| Finish | ENIG (fine-pitch QFN/DFN parts) or HASL |
| Min track/gap | per DRC net classes; power nets widened ([WI-EE-04 §4](../../analysis/WI-EE-04-pcb-layout.md)) |
| Min drill | 0.3 mm |
| Soldermask / silk | both sides; silk carries connector name/polarity/voltage/warnings (§7.9) |

Status LED PCB (PCB2): 2-layer, same finish, small front-panel board ([WI-EE-09](../../analysis/WI-EE-09-status-led-board.md)).

## 3. Generation (headless, no GUI)

```sh
electronics/pcb/programmatic/build.sh     # netlist -> tscircuit -> autoroute -> out/controller.gerbers.zip
```

This produces the draft Gerbers/drill/PnP/BOM + a `controller.kicad_pcb`. **Before fab**, the draft
needs: (1) real footprints for the ICs, connectors, and the ESP32-S3 module (the draft uses `pinrowN`
placeholders), and (2) a reviewed power/analog/thermal placement per
[`design-rules.md`](../../analysis/design-rules.md) — the autorouter does not encode it. The committed
electrical gate (`controller_netlist.py --selftest`) runs in CI alongside `bom_check.py` (spec §10.5).

## 4. BOM compliance (§16.1, §16.3)

- All §16.1 core-electronics rows present: MCU, temp/RH, moisture, reservoir, leak, pump driver
  (logic-level + flyback + current sense), LED-driver interface, status LEDs, **battery-backed RTC**
  (DR-05), certified 24 V PSU, locking/keyed connectors. *(Fan driver `D3`/`CN_FAN` kept **DNP** —
  no fan in V1, [ECO-001](../../analysis/ECO-001-fan-removal.md).)*
- **Grow light** carried as `LIGHT-CANDIDATE-60W` (panel) with full §16.3 data (power, PPFD/PPF,
  dimming, horticultural spectrum, thermal mounting, cert) so the gate runs — **status
  `CANDIDATE-DR01-PASS`**: both halves of DR-01 now pass
  ([WI-PL-06](../../../plan/work-items/01-plant-science/WI-PL-06-photometric-model.md) photometric +
  [WI-EE-10](../../analysis/WI-EE-10-thermal-budget-model.md) thermal). PL-06 shows a **panel** meets
  ≥0.6 uniformity at 150 mm; a bar needs ≥200–225 mm. The final procurement pick is outstanding; the
  100 W full-yield bar and a compact bar alternative are in `alternates.csv`.
- `python3 scripts/bom_check.py --strict electronics/bom/bom.csv` → **PASS**.

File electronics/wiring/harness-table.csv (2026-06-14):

connector_ref | connector_name | connector_type | pin | signal | polarity | voltage_v | wire_awg | wire_color | destination | strain_relief | notes
J_PWR | Power input | XT30 / 2-pos screw | 1 | +24V | + | 24 | 18 | red | External 24VDC PSU brick | grommet + clamp at case wall | fused F1 downstream; reverse-polarity protected
J_PWR | Power input | XT30 / 2-pos screw | 2 | GND | - | 0 | 18 | black | External 24VDC PSU brick | grommet + clamp at case wall
J_LED | Grow light | JST VH 4-pos keyed | 1 | +24V | + | 24 | 18 | red | LED bar/driver | clamp at light mount; service loop | supply tube must NOT cross this run (DR-08)
J_LED | Grow light | JST VH 4-pos keyed | 2 | GND | - | 0 | 18 | black | LED bar/driver | clamp at light mount
J_LED | Grow light | JST VH 4-pos keyed | 3 | LED_DIM | signal | 0-10/PWM | 24 | white | LED driver dim input |  | 0-10V or PWM per selected driver
J_LED | Grow light | JST VH 4-pos keyed | 4 | LED_NTC | signal | 0-3.3 | 26 | grey | LED heatsink NTC (optional) |  | DR-09 secondary thermal; ADC1
J_PUMP | Pump | JST VH 2-pos keyed | 1 | PUMP_+24V | + | 24 | 20 | red | Submersible pump | drip loop below electronics; clamp | low-side switched; flyback on board
J_PUMP | Pump | JST VH 2-pos keyed | 2 | PUMP_RET | switched- | 0 | 20 | black | Submersible pump | drip loop | returns to pump MOSFET drain
J_FAN | Fan (DNP - not fitted V1) | 4-pin fan / JST XH | 1 | GND | - | 0 | 26 | black | NOT FITTED - no fan in V1 (ECO-001) | n/a | fan-drive header DNP; no harness in V1
J_FAN | Fan (DNP - not fitted V1) | 4-pin fan / JST XH | 2 | +12V | + | 12 | 24 | yellow | NOT FITTED - no fan in V1 (ECO-001) | n/a | DNP
J_FAN | Fan (DNP - not fitted V1) | 4-pin fan / JST XH | 3 | FAN_PWM | signal | 3.3 | 28 | blue | NOT FITTED - no fan in V1 (ECO-001) | n/a | DNP; GPIO12 left unused
J_FAN | Fan (DNP - not fitted V1) | 4-pin fan / JST XH | 4 | FAN_TACH | signal | 3.3 | 28 | green | NOT FITTED - no fan in V1 (ECO-001) | n/a | DNP; GPIO13 left unused
J_MOIST | Moisture probe | JST PH 3-pos keyed | 1 | +3V3 | + | 3.3 | 26 | red | Capacitive soil probe | drip loop at pot; replaceable conn | corrosion-resistant probe
J_MOIST | Moisture probe | JST PH 3-pos keyed | 2 | GND | - | 0 | 26 | black | Capacitive soil probe | drip loop
J_MOIST | Moisture probe | JST PH 3-pos keyed | 3 | MOIST_SIG | signal | 0-3.0 | 26 | white | Capacitive soil probe |  | ADC1; analog
J_RES | Reservoir level | JST PH 3-pos keyed | 1 | RES_LOW_SW | signal | 3.3 | 26 | white | Float switch | drip loop at reservoir | closed=low; internal pullup
J_RES | Reservoir level | JST PH 3-pos keyed | 2 | GND | - | 0 | 26 | black | Float switch / analog sensor | drip loop
J_RES | Reservoir level | JST PH 3-pos keyed | 3 | RES_LEVEL_ADC | signal | 0-3.3 | 26 | grey | Analog level (optional) |  | ADC1
J_LEAK | Leak sensor | JST PH 2-pos keyed | 1 | LEAK_SENSE | signal | 3.3 | 26 | white | Conductive trace/rope on tray | route along tray; below water path | to on-board comparator; FW latches
J_LEAK | Leak sensor | JST PH 2-pos keyed | 2 | GND | - | 0 | 26 | black | Conductive trace/rope on tray
J_SENS | Temp/RH sensor | JST PH 4-pos keyed | 1 | +3V3 | + | 3.3 | 28 | red | SHT40 board | shaded mid-height mount; service loop | I2C 0x44
J_SENS | Temp/RH sensor | JST PH 4-pos keyed | 2 | GND | - | 0 | 28 | black | SHT40 board
J_SENS | Temp/RH sensor | JST PH 4-pos keyed | 3 | I2C_SDA | signal | 3.3 | 28 | white | SHT40 board |  | shared I2C; 4.7k pullup on board
J_SENS | Temp/RH sensor | JST PH 4-pos keyed | 4 | I2C_SCL | signal | 3.3 | 28 | green | SHT40 board |  | shared I2C
J_STATUS | Status LED board | JST XH 3-pos keyed | 1 | +5V | + | 5 | 26 | red | Front-panel LED board | clip behind front UI | WS2812 chain
J_STATUS | Status LED board | JST XH 3-pos keyed | 2 | GND | - | 0 | 26 | black | Front-panel LED board
J_STATUS | Status LED board | JST XH 3-pos keyed | 3 | STATUS_DATA | signal | 3.3 | 28 | white | Front-panel LED board |  | RMT data; series R on board
J_DBG | Debug UART | 2.54mm header 4-pos | 1 | +3V3 | + | 3.3 | n/a | red | Service tool (assembly only) | hidden in normal use
J_DBG | Debug UART | 2.54mm header 4-pos | 2 | UART0_TX | signal | 3.3 | n/a | white | Service tool
J_DBG | Debug UART | 2.54mm header 4-pos | 3 | UART0_RX | signal | 3.3 | n/a | green | Service tool
J_DBG | Debug UART | 2.54mm header 4-pos | 4 | GND | - | 0 | n/a | black | Service tool
J_USB | USB-C | USB-C receptacle | shell | USB-CDC | n/a | 5 | n/a | n/a | Flash + log capture | board edge | native USB-JTAG GPIO19/20

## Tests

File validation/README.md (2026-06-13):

# validation/

Test plans, measurement data, and trial records for OpenCanopy. Owned by the **Validation & QA**
track (spec §13). This track owns proving each V1 release criterion in spec §21.

## Layout

- `test-plans/` — dry-run, wet-run, thermal, acoustic, fault-injection, and grow-trial plans.
- `logs/` — captured firmware/device logs from validation runs.
- `photos/` — trial photos (CC BY 4.0 **only after** personal info is removed — see `LICENSES/`).
- `ppfd-measurements/` — PPFD/PPF maps and DLI calculations for the grow light.
- `thermal/` — canopy/LED/driver thermal measurements.
- `acoustic/` — fan/pump noise measurements.
- `grow-trials/` — end-to-end real-plant trial records.

## Release gate

V1 is tagged only when every acceptance criterion in spec §21 is met and documented here.

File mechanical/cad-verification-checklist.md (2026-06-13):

# CAD Verification Checklist (spec §12.1)

Mechanical track · covers WI-ME-01 … WI-ME-07. The numeric rows are **computed
from the parametric model** by `cad/source/verify.py` (run it to reproduce), so
this checklist cannot silently drift from the geometry.

```text
$ .venv-cad/bin/python mechanical/cad/source/verify.py
CHECK                             VALUE                 TARGET                       RESULT
Envelope (W x D x H)              468 x 314 x 700 mm    <= 480 x 320 x 700           PASS
Frame interior (W x D)            428 x 268 mm          info                         PASS
Pot usable capacity               9.7 L                 8-10 L compact               PASS
Pot OD vs interior depth          250 vs 268 mm         clearance 18 mm > 0          PASS
Reservoir usable capacity         4.1 L                 2.5-4 L compact              PASS
LED clearance above pot rim       159 mm                150-300 mm                   PASS
Reservoir top vs pot deck         146 vs 180 mm         withdraws below the deck     PASS
CG height (full + plant)          305 mm (44% H)        bottom-heavy (< 50% H)       PASS
Cable bend / drip-loop radius     20 mm                 drip loop before bay         PASS
CAD verification: PASS
```

## §12.1 line items

| # | Check | Status | Evidence |
|---|---|---|---|
| 1 | Full assembly CAD complete | ✅ | `cad/source/opencanopy/assembly.py`; `cad/step/opencanopy-assembly.step` |
| 2 | Pot inserted/removed path checked | ✅ | Pot lifts off the locating ring (10 mm) into 159 mm of headroom, then withdraws through the open front; light mount raises on its adjustment row if needed. |
| 3 | Reservoir inserted/removed path checked | ✅ | Reservoir top 146 mm < pot deck 180 mm → the drawer slides out the front on the cradle rails **without** disturbing the pot/plant (§8.4). |
| 4 | Pump/filter access checked | ✅ | Pump sits in the reservoir on the open-front C-clip (`pump-clip`); lift the reservoir, lift the pump out — tool-free. |
| 5 | Cable bend radius checked | ✅ | Drip-loop / min-bend radius 20 mm enforced at every dry-bay grommet entry; channel mouths are radiused. |
| 6 | Tubing path checked | ✅ | Tube runs in the dedicated channel pocket (separate from wiring), visible/inspectable, clipped with `tube-clip`. |
| 7 | LED height/clearance checked | ✅ | 159 mm above the pot rim at the nominal carrier hole, adjustable 150–300 mm (§8.6). |
| 8 | Fan clearance checked | ✅ | Fan offset +80 mm in X and high at the rear → circulation across, not a stream into, the canopy; guard present. |
| 9 | Electronics bay access checked | ✅ | Top-removable lid; serviced without opening the wet bay (§8.4). |
| 10 | Tool access checked | ✅ | Reservoir, pump and pot are tool-free; only heat-set/screw bosses need a driver, all reachable from the open front/top. |
| 11 | Center of gravity (full reservoir + plant) | ✅ | CG at 305 mm = 44 % of height; water + media + pot dominate and sit low → bottom-heavy/stable. |
| 12 | Drip/leak path checked | ✅ | Pot overflow → pot-tray gutter → downspout → leak tray → sensor sump. Reservoir overflow → front weir (away from rear/upper electronics). |
| 13 | Interference / clearance (worst case) | ✅ | `collision_check.py` (FCL on the real models): zero collisions; every clearance ≥2 mm, survives a 1.0 mm worst-case FDM closure budget. Details in `tolerance-analysis.md`. |

## "Water fails downward; electronics live upward" (§6.2)

`assembly.assert_zone_separation()` proves no part tagged *dry* (electronics bay +
lid) intrudes below the pot-deck Z (180 mm). The only water-carrying parts
(reservoir, pump, leak tray, pot tray) are the lowest modules; the electronics bay
is the topmost module. This is asserted on every build — see `build.py` output.

## Interface assumptions published to other tracks

* **Electronics (WI-EE-04):** the dry bay reserves a **120 × 90 mm** controller-PCB
  envelope with M3 heat-set bosses on an 8 mm-inset pattern, plus a 110 × 40 mm
  remote-driver footprint. The EE-04 layout report (`electronics/analysis/`)
  reciprocally states the board outline + mount-hole pattern are *"coordinated with
  the mechanical electronics-bay before fabrication"* — i.e. the outline is **not yet
  frozen on either side**; this reserved envelope is the coordination point. When the
  KiCad board lands, confirm it fits and update `PCB_W/PCB_D` in `params.py` (a
  change-controlled value) if needed.
* **Electronics (WI-EE-05):** cable-channel and dry-bay entries are labelled
  `pump / fan / led / moisture / reservoir / leak`. Verified against the landed
  `electronics/wiring/harness-table.csv` — connectors `J_PUMP / J_FAN / J_LED /
  J_MOIST / J_RES / J_LEAK` match; the table also has a `J_PWR` 24 V PSU input
  (XT30/screw) which enters the bay through its own grommet + drip loop. Field
  connectors are keyed JST VH/XH/PH, which the channel pockets and grommet bores clear.
* **Light (§16.3):** the LED head is modelled at 320 × 120 × 30 mm, 50–80 W remote
  driver; secondary-retention eyelets (Ø4 mm tether) are provided regardless of the
  exact fixture chosen.

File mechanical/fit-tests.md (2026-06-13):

# Fit tests — tolerance coupons (spec §12.2)

Print the coupon set in `stl/prototypes/` **before** committing the large parts,
then record results here and fold the winning clearances back into
`cad/source/opencanopy/params.py`. Coupons are graded (a few values bracketing the
nominal) so you can pick what fits your printer/material.

> **Note:** the *assembly* fit risk is already retired by simulation — see
> [`tolerance-analysis.md`](tolerance-analysis.md). Every clearance fit has ≥2 mm gap
> and survives a worst-case FDM error band (validated with FCL on the real models).
> These coupons therefore **confirm the process band** (does *this* printer fall
> within the assumed 0.3 mm growth / 0.2 mm position?) rather than discover fits — one
> coupon print validates the whole assembly.

## Coupon set (the seven §12.2 coupons)

| Coupon (STL) | Tests | Graded values |
|---|---|---|
| `coupon-snap-fit` | cantilever flex without cracking | single 3.0 mm finger + hook |
| `coupon-screw-boss` | M3 self-tapping pilot | pilot Ø 2.5 / 2.7 / 2.9 mm |
| `coupon-heatset-insert` | M3 brass heat-set bore | bore Ø 3.8 / 4.0 / 4.2 mm |
| `coupon-tube-clip` | 8 mm tube snap grip | gap 0.2 / 0.4 / 0.6 mm |
| `coupon-diffuser-slot` | 6 mm diffuser strip slot | slot 6.0 / 6.2 / 6.4 mm |
| `coupon-cable-channel-clip` | retaining-lip snap on a wire bundle | single (lip = channel) |
| `coupon-reservoir-rail` | sliding rail/slider | `CLEAR_SLIDE` = 0.30 mm |

## Acceptance (§12.2)

- [ ] No cracking (snap-fit flexes and returns; no whitening/fracture).
- [ ] No excessive force (parts assemble by hand, no tools/hammering).
- [ ] No sharp edges near tubing (tube clip and channel mouths deburred/radiused).
- [ ] No loose fan/light mounts (mount bosses hold M3 without spin-out).
- [ ] Parts survive 40 °C for 4 h without warping (heat-soak the coupon set).

## Results log

Fill one block per print run. Status stays **PENDING** until the physical alpha
print is made — these are the design-side coupons; the build is owned jointly with
the Validation track (WI-QA cluster) and the alpha build (WI-ME-08).

```text
Run:            <date>
Printer:        <model>
Material:       <PETG/ASA, brand, colour>
Nozzle/layer:   0.4 mm / 0.20 mm
Bed/hotend:     <°C / °C>

Coupon              Best value      Pass?   Notes
snap-fit            -               -       flex/crack check
screw-boss          pilot 2.? mm    -       which pilot held best
heatset-insert      bore 4.? mm     -       insert flush & square?
tube-clip           gap 0.? mm      -       grips 8 mm tube, removable
diffuser-slot       slot 6.? mm     -       strip slides, no rattle
cable-channel-clip  -               -       bundle retained, releasable
reservoir-rail      0.30 mm         -       slides freely, no slop
40 °C heat-soak     -               -       any warp/deform?
```

> **Status:** PENDING physical print. Coupons are modelled, exported, and
> manifold-clean (CI `stl_check`). Once printed, record the chosen clearances above
> and update `params.py`, then `python mechanical/cad/source/build.py` to propagate.

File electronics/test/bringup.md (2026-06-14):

<!-- SPDX-License-Identifier: CC-BY-4.0 -->
# WI-EE-08 — Board bring-up procedure

**Status:** Procedure authored (ready to execute). **Execution BLOCKED only on a fabricated board** —
[WI-FW-07 safety state machine](../../plan/work-items/02-firmware/WI-FW-07-safety-state-machine.md) is
now **Done** and host-tested, so the firmware that steps 6–13 flash *exists* and its logic is already
dry-validated off-silicon (122 host tests + Wokwi). The `blocked` rows below await **silicon**, not
firmware. **No fan in V1** ([ECO-001](../analysis/ECO-001-fan-removal.md)) — fan steps struck.
**Spec refs:** §11.2, §9.9, §11.4.

> Fill the **Result** column as each step is performed. Do **not** advance past a failed safety step
> (continuity, fail-off, leak lockout). Power throughout step 3+ comes from a **current-limited bench
> supply** set to the rail's expected draw + margin.

## A. Power-off checks (no firmware needed)

| # | Step (§11.2) | Pass criterion | Result |
|---|---|---|---|
| 1 | Visual inspection | No bridges, correct polarity, parts seated | `pending` |
| 2a | Continuity: 24 V↔GND | **No short** | `pending` |
| 2b | Continuity: 12 V↔GND | No short | `pending` |
| 2c | Continuity: 5 V↔GND | No short | `pending` |
| 2d | Continuity: 3.3 V↔GND | No short | `pending` |
| 2e | **Pump gate→GND** | ~10 kΩ pull-down present (fail-OFF guarantee, §9.6) | `pending` |

## B. Power-on, rails (current-limited supply)

| # | Step | Pass criterion | Result |
|---|---|---|---|
| 3 | Apply 24 V via current-limited supply, watch current | No fault current; reverse-polarity + fuse intact | `pending` |
| 4 | Verify rails **unloaded** | 24/12/5/3.3 V within ±5 % at test points | `pending` |
| 5 | Verify regulator temperatures | All regulators stable, within rating (cross-check [WI-EE-06 T5](pcb-verification.md)) | `pending` |

## C. MCU & I/O (requires firmware — **blocked on WI-FW-07 build**)

| # | Step | Pass criterion | Result |
|---|---|---|---|
| 6 | Flash test firmware (USB-CDC) | Boots; runs SELF_TEST (§9.4) | `blocked` |
| 7 | Verify USB/UART | Log stream over USB-CDC and UART header | `blocked` |
| 8 | Verify each sensor bus | I²C enumerates SHT40/DS3231/INA219; ADC1 reads moisture/leak/reservoir | `blocked` |
| 9 | Verify each output with **dummy load** | pump/LED-dim lines toggle as commanded | `blocked` (board) |
| 10 | **Pump MOSFET with real pump in water** | Pumps when commanded; **off on reset/crash** (fail-OFF) | `blocked` (board) |
| ~~11~~ | ~~Fan PWM + tach~~ | **N/A — no fan in V1 (ECO-001)**; GPIO12/13 left unused | `n/a` |
| 12 | LED dimming with driver | Dim command changes output; driver foldback honoured (DR-09) | `blocked` |
| 13 | Status LED board | All 5 positions + all patterns (§7.11) | `blocked` |

## D. Soak

| # | Step | Pass criterion | Result |
|---|---|---|---|
| 14 | 24 h **dry** burn-in (no water) | No resets/thermal faults; logs clean | `blocked` |
| 15 | 24 h **wet-bay** test (water, no plant) | No leaks; leak lockout armed; rails stable | `blocked` |

## E. Calibration (§9.9 — values populate [WI-FW-11 NVS schema](../../plan/work-items/02-firmware/WI-FW-11-calibration-storage.md))

| Calibration | Method (§9.9) | Output key | Result |
|---|---|---|---|
| Moisture dry/wet | dev mode, chosen media (4-point per §7.6) | `moisture_raw_dry`, `moisture_raw_wet` | `blocked` |
| Pump ml/s | run into cylinder 30 s | `pump_ml_per_sec` | `blocked` |
| Reservoir low point | fill–drain | `reservoir_low_adc` | `blocked` |
| ~~Fan min PWM~~ | ~~lowest reliable spinning duty~~ | ~~`fan_min_pwm`~~ | **N/A — no fan in V1 (ECO-001)** |
| LED PPFD map | PAR grid @25/50/75/100 % | `led_ppfd_map` | `blocked` (needs PL-06 + light) |
| Temp/RH sanity | vs reference | (validation note) | `blocked` |
| Leak | wet test | (verify lockout latch) | `blocked` |

## Acceptance (spec §15.5 M4-08)

Rails, MCU, sensors, outputs all pass → sign here. **Hardware fail-off (step 10) and leak lockout
(step 15 + HIL) are gating** and must pass before any live-plant loop.

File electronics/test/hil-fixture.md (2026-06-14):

<!-- SPDX-License-Identifier: CC-BY-4.0 -->
# WI-EE-08 — Hardware-in-loop (HIL) fixture & automated fault tests

**Status:** Fixture design + automated test matrix authored; **logic half now dry-validated against
the firmware host-tests** (see §2.1). **Hardware execution BLOCKED only on a fabricated board** —
[WI-FW-07 safety state machine](../../plan/work-items/02-firmware/WI-FW-07-safety-state-machine.md) is
now **Done** and host-tested, so the state-machine behaviour these fault tests assert is implemented
and proven off-silicon; what remains is proving it **on the device**.
**Spec refs:** §10.4, §11.2, §9.3, §9.9.
**Lives with:** [`firmware/hil/`](../../firmware/hil/) (fixture firmware/fixtures) — this doc is the
electronics-side fixture spec.
**No fan in V1** ([ECO-001](../analysis/ECO-001-fan-removal.md)) — the fan PWM/tach channel (H6) is
struck.

## 1. Fixture design (§10.4)

A bench fixture that presents the controller's real connectors with programmable stimuli and captures
its outputs, so fault scenarios run automatically and repeatably:

| Channel | Stimulus / capture | Drives controller's | Maps to |
|---|---|---|---|
| Programmable moisture | DAC or digipot on `MOIST_SIG` (or digital mock) | moisture ADC (GPIO4) | §10.4 |
| Reservoir switch sim | relay/FET across float-switch pins | `RES_LOW_SW` (GPIO5) | §10.4 |
| Leak switch sim | relay across leak comparator input | `LEAK_DET` path (GPIO7) | §10.4 |
| Pump dummy load | resistor/electronic load + current shunt on `J_PUMP` | pump MOSFET drain | §10.4 |
| ~~Fan tach sim~~ | **N/A — no fan in V1 (ECO-001)** | GPIO13 unused | — |
| LED dim dummy | scope/ADC on `LED_DIM` | LED dim (GPIO14) | §10.4 |
| Current measurement | shunt + ADC on pump/24 V | INA219 cross-check | §10.4 |
| UART log capture | host serial on `J_DBG`/USB-CDC | logs (§9.10) | §10.4 |

The fixture host (PC or a second MCU) sets stimuli, reads the controller's UART log + captured
outputs, and asserts the expected state/output per case.

## 2. Automated test matrix (§10.4 + §9.3 priorities)

| # | Scenario | Stimulus | Expected (asserted) | State (§9.3) |
|---|---|---|---|---|
| H1 | Boot self-test | power-on | SELF_TEST runs, pump confirmed OFF (§9.4) | BOOT→SELF_TEST→NORMAL |
| H2 | **Leak → pump lockout** | assert leak while watering | pump output **never enables**; latched until manual clear (§11.4) | LEAK_DETECTED (highest) |
| H3 | **Low-water → no pump** | reservoir-low asserted | pump **never enables** | LOW_WATER |
| H4 | Leak priority over low-water | both asserted | LEAK_DETECTED wins (§9.3 priority) | LEAK_DETECTED |
| H5 | LED dim command changes | command 25/50/75/100 % | LED_DIM output tracks command | NORMAL |
| ~~H6~~ | ~~Fan PWM changes~~ | **N/A — no fan in V1 (ECO-001)** | — | — |
| H7 | Status LED patterns | drive each fault | correct colour/position/pattern (§7.11) | per fault |
| H8 | **Watchdog resets safely** | stall firmware loop | watchdog fires; on reset **pump OFF** (gate pull-down) | →BOOT, pump OFF |
| H9 | Sensor fault → safe | implausible moisture | auto-water disabled, fault shown (§7.6) | SENSOR_FAULT |
| H10 | Over-temp derate | inject high air-temp | LED derates per §9.5 ladder | OVER_TEMP |

H2, H3, H4, H8 are the **gating safety tests** (spec §15.5 M4-09): pump lockout proven *in hardware*,
not just simulation (this is exactly the DR-02 gap — sim proves logic, HIL proves the device).

## 2.1 Logic half — dry-validated against firmware host-tests (no silicon)

With [WI-FW-07](../../plan/work-items/02-firmware/WI-FW-07-safety-state-machine.md) **Done**, each H-case's
*logic* is now provable off-silicon by an existing `cargo test` in the host-tested `control` crate.
This **closes the logic half of the DR-02 gap ahead of fabrication**; the hardware column is what the
board run still has to prove (real fail-off voltage, the watchdog actually firing, real PPFD/current).

| # | Logic dry-validated by (host test) | What still needs the board |
|---|---|---|
| H1 | `app_state::boots_to_normal_with_valid_calibration`, `…missing_calibration_disables_watering_and_faults`; `safety_controller::boot_with_bad_calibration_does_not_reach_normal` (pump forced off at boot, §9.4) | SELF_TEST runs on real peripherals; pump line measured OFF |
| **H2** | `app_state::leak_gate_overrides_everything`; `safety_controller::leak_latches_until_manual_clear`; `hal_integration::injected_leak_keeps_pump_trait_deenergized` | MOSFET drain measured dead while leak asserted; latch across power-cycle |
| **H3** | `safety_controller::sensor_fault_and_low_water_block_pump` | reservoir-low float → pump line OFF on the DUT |
| **H4** | `safety_controller::leak_beats_everything`, `…priority_ladder_each_rung` | both inputs asserted on hardware → LEAK wins |
| H5 | `light_controller::commanded_power_combines_schedule_ramp_and_derate` (+ `app_state` led_pct path) | LED_DIM output measured at 25/50/75/100 % |
| ~~H6~~ | — (no fan in V1, ECO-001) | — |
| H7 | `led_status::sensor_fault_is_distinct_double_blink`, `…night_mode_dims_greens_but_keeps_system_heartbeat`, `…rtc_fallback_shows_amber_system_pulse` | WS2812 colour/pattern on the real status board (RMT driver — see gaps) |
| **H8** | boot forces pump off (`safety_controller::boot`); **hardware fail-off is firmware-independent** — gate pull-down `R1`, [WI-EE-03 §5.1](../analysis/WI-EE-03-schematic.md) | watchdog (RWDT) actually fires & resets; pump measured OFF through the reset |
| H9 | `app_state::missing_calibration_disables_watering_and_faults`; `hal_integration::injected_moisture_fault_disables_watering` | implausible moisture on real ADC → SENSOR_FAULT |
| H10 | `app_state::over_temp_cuts_led_and_pump`; `light_controller::air_temp_derate_thresholds` | inject real air-temp; LED derate measured (no fan branch — LED-off is the live mitigation) |

So **9 of 10 cases** have their logic proven off-silicon today (H6 is gone). Only the *device-physics*
half — fail-off voltage, watchdog firing, real PPFD/current/LED-status — waits on a fabricated board.

## 2.2 Open integration gap — INA219 over-current → pump fault (DR-04)

The BOM carries the **INA219 pump-current monitor as "required V1"** (`U4`, DR-04: clog/dry-run
detection). The firmware **reads** it (`controller/src/hw.rs` `read_ina219_ma`, logged each tick) but
the current does **not yet feed pump-fault arbitration**: `SafetyInputs.pump_fault`
(`control/src/app_state.rs`) is driven only by the irrigation controller's **flow-based** no-rise /
watering-limit logic — `SensorFrame` has no pump-current field, so an **over-current/clog never
latches `PUMP_FAULT`**. Test **H-INA** to add when the path is wired (firmware item, host-testable
now; no silicon needed):

| # | Scenario | Stimulus | Expected (asserted) | State |
|---|---|---|---|---|
| H-INA | Pump over-current / clog | shunt current above the DR-04 threshold | `PUMP_FAULT` latches; pump locked out | PUMP_FAULT |

This is flagged to the firmware track; the HIL fixture's current shunt on `J_PUMP` already provides
the stimulus, so H-INA runs on the same rig once the firmware threshold lands.

## 3. Calibrations run on the fixture (§9.9)

The §9.9 calibrations (moisture dry/wet, pump ml/s, LED PPFD map, reservoir low — **fan-min-PWM
struck, no fan in V1, ECO-001**) are run here and their values populate the
[WI-FW-11 NVS schema](../../plan/work-items/02-firmware/WI-FW-11-calibration-storage.md).
Procedure + result table is in [bringup.md §E](bringup.md).

## 4. Blocking dependencies

| Blocker | Why it blocks | Tracks | State |
|---|---|---|---|
| Fabricated controller board | No DUT to bring up / wire to the fixture | follows [WI-EE-07](../pcb/fabrication/fab-notes.md) Gerber export | **the only remaining blocker** |
| ~~WI-FW-07 safety state machine~~ | ~~H1–H10 assert state/priority/fail-off behaviour~~ | [02-firmware](../../plan/work-items/02-firmware/WI-FW-07-safety-state-machine.md) | **✔ Done** — logic dry-validated (§2.1) |
| ~~WI-FW-08/04/05/06 controllers~~ | ~~LED/pump command tests need the controllers~~ | 02-firmware | **✔ Done** |

WI-FW-07 has landed: the matrix logic is **dry-validated against the firmware host-tests today**
(§2.1). When a board is fabricated, the same matrix runs unchanged to prove the device-physics half.

## 5. Deliverable status

| Deliverable | State |
|---|---|
| Bring-up per §11.2 | procedure ✔ ([bringup.md](bringup.md)); execution ⛔ blocked on **board only** (FW-07 done) |
| Pump-in-water / LED / status verify | procedure ✔; execution ⛔ blocked on board (fan struck — ECO-001) |
| 24 h dry + 24 h wet soak | procedure ✔; execution ⛔ blocked on board |
| HIL fixture (§10.4) | design ✔ (this doc); build ⛔ pending |
| Automated HIL fault tests | matrix ✔ (H1–H10); **logic half ✔ dry-validated (§2.1)**; device run ⛔ blocked on board |
| §9.9 calibrations → WI-FW-11 | procedure ✔; values ⛔ blocked on board (fan-min-PWM struck — ECO-001) |

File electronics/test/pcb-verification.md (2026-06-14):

<!-- SPDX-License-Identifier: CC-BY-4.0 -->
# WI-EE-06 — Trace current & thermal verification report

**Status:** Trace-width calc, max-current table, connector ratings, and predicted voltage drop /
component temperatures **complete (computed)**. The **measured** voltage drop, MOSFET/regulator
temperatures, and thermal-camera image are recorded at board bring-up
([WI-EE-08](bringup.md) → this file), and require a fabricated board.
**Spec refs:** §7.10, §11.3.
**Reproduce calc:** `python3 electronics/analysis/trace_width.py`.

## 1. Trace-width calculation & max-current table (§11.3) — computed

IPC-2221, 10 °C allowed rise, 1 oz outer copper. `used_w` carries ≥1.5× margin over the IPC minimum;
the 24 V/LED paths are realised as **filled copper pours** ≥ `used_w` (see [WI-EE-04](../analysis/WI-EE-04-pcb-layout.md)).

| Power path | Worst-case I | IPC min width | Used width | Predicted V-drop (1-way) |
|---|---:|---:|---:|---:|
| 24 V input → regulators/LED | 4.20 A | 2.17 mm | 3.3 mm / pour | 37.8 mV |
| LED driver feed (24 V) | 4.20 A | 2.17 mm | 3.3 mm / pour | 25.2 mV |
| Pump MOSFET drain/source | 0.63 A | 0.16 mm | 0.3 mm + pour | 31.2 mV |
| 12 V rail (optional 12 V pump only; no fan — ECO-001) | 1.70 A | 0.62 mm | 0.9 mm | 46.8 mV |
| 5 V rail | 0.60 A | 0.15 mm | 0.3 mm | 49.6 mV |
| 3V3 rail (MCU) | 0.60 A | 0.15 mm | 0.3 mm | 39.6 mV |

All predicted drops are <50 mV — negligible against rail tolerances. The LED feed is the only path
near 4 A; the pour keeps its rise and drop low.

## 2. Predicted component temperatures (to be confirmed by measurement)

| Component | Loss (computed) | Prediction | Basis |
|---|---:|---|---|
| Pump MOSFET @ peak | ~12–30 mW (I²R, logic-level FET R_DS(on)≈30 mΩ, ≤1 A) | <5 °C rise — effectively ambient | low current + copper pour |
| 24→12 V buck @ 1.7 A *(optional/DNP)* | ~2.2 W (η≈0.90) | ~30–40 °C rise with pour → confirm <125 °C | **only if the 12 V pump option is fitted**; default 24 V-pump build omits this buck entirely (no fan — ECO-001) |
| 24→5 V buck @ 0.6 A | ~0.4 W | small rise | — |
| 5→3.3 V reg @ 0.6 A | ~0.3 W | small rise | — |

The big LED-driver dissipation is in the **remote driver module**, not on the controller PCB; the
controller only passes 24 V through to the LED connector (pour). Its thermal envelope is the
[WI-EE-10 model](../analysis/WI-EE-10-thermal-budget-model.md).

## 3. Connector current-rating table (§11.3) — computed

Carried from [WI-EE-02 §4](../analysis/power-budget.md):

| Connector | Worst-case I | Selection | Rated |
|---|---:|---|---:|
| J_PWR (24 V in) | 6.25 A | XT30 / 2-pos screw | ≥10 A |
| J_LED (24 V) | 4.2 A | JST VH | ≥6 A |
| J_PUMP (24 V) | 0.63 A | JST VH | ≥3 A |
| ~~J_FAN (12 V)~~ | — | **DNP — no fan in V1 (ECO-001)** | — |
| Sensor buses | <0.1 A | JST PH/XH | ≥1 A |

## 4. Measurement templates — fill at bring-up (WI-EE-08)

> These require the fabricated board powered from a current-limited bench supply.

| ID | Measurement | Method | Pass criterion | Measured |
|---|---|---|---|---|
| T1 | 24 V feed V-drop @ 4.2 A | DMM across input→LED connector at max load | within prediction; <100 mV | `pending` |
| T2 | 12 V V-drop @ full load | DMM across buck out→12 V pump | <100 mV | `pending` *(only if 12 V pump option fitted; no fan)* |
| T3 | Pump MOSFET temp @ 100 % | thermocouple / IR on FET, real pump in water | < FET rating, < 60 °C case | `pending` |
| ~~T4~~ | ~~Fan-drive temp @ 100 %~~ | **N/A — no fan in V1 (ECO-001)** | — | `n/a` |
| T5 | Regulator temps @ worst-case ambient | IR on each DC/DC at 25–40 °C bay | junction < rating | `pending` |
| T6 | Thermal-camera image @ max pump/LED-control load | thermal cam, full-load steady state | no hotspot over rating | `pending` (save to `validation/thermal/`) |

## 5. Deliverable status

| Deliverable | State |
|---|---|
| Trace-width calc + max-current table | ✔ computed |
| Voltage-drop measurement under max load | predicted ✔ / **measured ⏳** (T1–T2) |
| MOSFET temp @100 % pump; regulator temp worst-case (no fan — ECO-001) | predicted ✔ / **measured ⏳** (T3, T5) |
| Thermal-camera image at max load | template ✔ / **image ⏳** (T6) |
| Connector current-rating table | ✔ computed |

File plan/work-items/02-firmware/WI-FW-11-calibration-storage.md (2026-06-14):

# WI-FW-11 — Calibration storage

| Field | Value |
|---|---|
| Track | Firmware |
| Milestone | (supports M3, M6) |
| Depends on | WI-FW-02 |
| Spec refs | §9.9, §7.6 |
| Status | Done |

## Objective

Implement persistent calibration storage that separates hidden/developer calibration from user
config, with safe handling of missing/corrupt data.

## Deliverables

- [x] Flash-backed calibration store (e.g. `esp-storage` + `sequential-storage`, no ESP-IDF NVS) for
      the §9.9 schema: `moisture_raw_dry/wet`, `led_ppfd_map`, `reservoir_low_adc`. Serialize with a
      `no_std` codec (e.g. `postcard`). *(`fan_min_pwm` removed with the fan (ECO-001) and
      `pump_ml_per_sec` removed with the pump (ECO-003); the record is now schema **v4**, 24 bytes,
      so any old 28/30-byte blob fails the length check → fail-safe. Spec §9.9 still lists the dropped
      fields and needs the Project track's pass.)*
- [x] Safe defaults + validation: missing/corrupt calibration disables auto-watering and raises fault
      rather than acting on bad data (§7.6 fail-safe).
- [x] Calibration version stamped into logs.
- [x] Unit tests for defaults, missing, and corrupt calibration (spec §10.2 "Calibration store (flash)").

## Acceptance criteria

- Defaults/missing/corrupt calibration tests pass.
- Implausible moisture reading disables auto-watering and shows fault (§7.6).

## Implementation

- `control/src/calibration.rs`: the §9.9 schema, a dependency-free fixed-layout codec with a
  CRC32 trailer (host-testable; `postcard`/`sequential-storage` are the on-target swap-in), plus
  `validate()`/`load()` implementing the §7.6 fail-safe — missing/corrupt/implausible calibration
  disables auto-watering and raises a fault rather than acting on bad data. Calibration `version`
  is stamped into the log at boot. Host-tested (defaults, missing, corrupt-CRC, truncated,
  implausible). Flash IO is the `controller/` binding (esp-storage), verified at bring-up.

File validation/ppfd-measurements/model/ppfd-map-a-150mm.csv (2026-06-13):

y_mm\x_mm | -175 | -150 | -125 | -100 | -75 | -50 | -25 | 0 | 25 | 50 | 75 | 100 | 125 | 150 | 175
-130 | 247 | 270 | 290 | 306 | 318 | 327 | 331 | 333 | 331 | 327 | 318 | 306 | 290 | 270 | 247
-104 | 310 | 343 | 370 | 392 | 407 | 418 | 424 | 426 | 424 | 418 | 407 | 392 | 370 | 343 | 310
-78 | 385 | 429 | 465 | 493 | 512 | 525 | 533 | 535 | 533 | 525 | 512 | 493 | 465 | 429 | 385
-52 | 463 | 518 | 563 | 597 | 620 | 636 | 644 | 647 | 644 | 636 | 620 | 597 | 563 | 518 | 463
-26 | 523 | 589 | 640 | 679 | 705 | 722 | 732 | 735 | 732 | 722 | 705 | 679 | 640 | 589 | 523
0 | 547 | 616 | 670 | 710 | 738 | 755 | 765 | 768 | 765 | 755 | 738 | 710 | 670 | 616 | 547
26 | 523 | 589 | 640 | 679 | 705 | 722 | 732 | 735 | 732 | 722 | 705 | 679 | 640 | 589 | 523
52 | 463 | 518 | 563 | 597 | 620 | 636 | 644 | 647 | 644 | 636 | 620 | 597 | 563 | 518 | 463
78 | 385 | 429 | 465 | 493 | 512 | 525 | 533 | 535 | 533 | 525 | 512 | 493 | 465 | 429 | 385
104 | 310 | 343 | 370 | 392 | 407 | 418 | 424 | 426 | 424 | 418 | 407 | 392 | 370 | 343 | 310
130 | 247 | 270 | 290 | 306 | 318 | 327 | 331 | 333 | 331 | 327 | 318 | 306 | 290 | 270 | 247

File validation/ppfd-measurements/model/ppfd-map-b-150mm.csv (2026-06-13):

y_mm\x_mm | -175 | -150 | -125 | -100 | -75 | -50 | -25 | 0 | 25 | 50 | 75 | 100 | 125 | 150 | 175
-130 | 370 | 405 | 435 | 459 | 478 | 490 | 497 | 499 | 497 | 490 | 478 | 459 | 435 | 405 | 370
-104 | 465 | 514 | 555 | 587 | 611 | 627 | 636 | 639 | 636 | 627 | 611 | 587 | 555 | 514 | 465
-78 | 578 | 644 | 698 | 739 | 769 | 788 | 799 | 803 | 799 | 788 | 769 | 739 | 698 | 644 | 578
-52 | 694 | 777 | 845 | 895 | 930 | 953 | 966 | 971 | 966 | 953 | 930 | 895 | 845 | 777 | 694
-26 | 785 | 883 | 961 | 1018 | 1058 | 1083 | 1097 | 1102 | 1097 | 1083 | 1058 | 1018 | 961 | 883 | 785
0 | 821 | 924 | 1006 | 1065 | 1107 | 1133 | 1148 | 1153 | 1148 | 1133 | 1107 | 1065 | 1006 | 924 | 821
26 | 785 | 883 | 961 | 1018 | 1058 | 1083 | 1097 | 1102 | 1097 | 1083 | 1058 | 1018 | 961 | 883 | 785
52 | 694 | 777 | 845 | 895 | 930 | 953 | 966 | 971 | 966 | 953 | 930 | 895 | 845 | 777 | 694
78 | 578 | 644 | 698 | 739 | 769 | 788 | 799 | 803 | 799 | 788 | 769 | 739 | 698 | 644 | 578
104 | 465 | 514 | 555 | 587 | 611 | 627 | 636 | 639 | 636 | 627 | 611 | 587 | 555 | 514 | 465
130 | 370 | 405 | 435 | 459 | 478 | 490 | 497 | 499 | 497 | 490 | 478 | 459 | 435 | 405 | 370

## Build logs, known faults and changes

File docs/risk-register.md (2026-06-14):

# OpenCanopy V1 — Risk Register

**Status:** Live · **Owner:** Project & Repo track · **Spec refs:** §22 (key engineering risks), §17 (safety)

This register tracks the engineering and safety risks called out by the spec, each with a likelihood,
impact, owning track, mitigation, and the work item(s) that close or verify it. It is the change-control
ledger for the project: any change to a locked requirement
([`product-requirements.md`](product-requirements.md)) or any reopened non-goal
([`scope.md`](scope.md)) must be logged here.

**Scales.** Likelihood: Low / Medium / High (chance the risk materializes if unmitigated).
Impact: Low / Medium / High / **Critical** (Critical = safety or project-killing). Work-item IDs link
to `../plan/work-items/`.

**Basis.** The plant-facing risks (R1 light, R2 root volume, R3 overwatering, R6 yield expectations)
are grounded in extension/research guidance — see [`references.md`](references.md) and spec §2. For
example, R3's overwatering/blossom-end-rot link comes from sources R5/R8/R15/R16; R1's DLI/PPFD framing
from R1/R2/R3.

> **🔄 REDESIGN — [ECO-003](ECO-003-v1-redesign.md) (2026-06-14).** V1 moved to a two-pillar form with
> **electronics in the top block** and **passive self-watering (no pump, no fan)**. This **changes or
> retires several risks below** — kept for ledger history, annotated, not deleted:
> **R3** overwatering → far lower (no pump; passive cannot flood); **R4/S2** isolation → now **top
> (electronics) vs bottom (water)**, not an in-base wall; **R5/S14/S18** (fan) → moot ([ECO-001](../electronics/analysis/ECO-001-fan-removal.md));
> **S5/S6/S7/S20** (pump lockout / fail-off / flood caps / impeller access) → **N/A, no pump**; **R8**
> (pump-fail-off HIL) → pump portion N/A. New redesign risks **R9–R14** are in **§C** below.

---

## A. Key engineering risks (spec §22)

| # | Risk | Likelihood | Impact | Owning track | Mitigation | Mitigating / closing work item(s) |
|---|---|---|---|---|---|---|
| R1 | Underpowered or poorly specified grow light (low PPFD/DLI, vague "plant lamp") | Medium | High | Electronics + Plant Science | Lock DLI/PPFD targets; require real photometric/thermal/safety data in BOM; CI rejects underspecified lights; verify with PPFD map and grow trial | [WI-PL-02](../plan/work-items/01-plant-science/WI-PL-02-light-dli-targets.md), [WI-EE-01](../plan/work-items/03-electronics/WI-EE-01-component-poc.md), [WI-PS-06](../plan/work-items/00-project-setup/WI-PS-06-ci-pipeline.md) (bom_check §16.3), verified by [WI-QA-07](../plan/work-items/05-validation-qa/WI-QA-07-grow-trial.md) |
| R2 | Too-small pot / insufficient root volume | Medium | High | Mechanical + Plant Science | Lock pot at top of compact band (10 L) with 12–19 L full-yield variant; fit-test removable pot | [WI-PS-04](../plan/work-items/00-project-setup/WI-PS-04-requirements-scope-lock.md), [WI-ME-02](../plan/work-items/04-mechanical/WI-ME-02-pot-reservoir-fit.md), [WI-PL-01](../plan/work-items/01-plant-science/WI-PL-01-lifecycle-profile.md) |
| R3 | Overwatering from bad moisture calibration | High | High | Firmware + Validation | Stage-specific moisture thresholds; watering windows + daily/runtime caps; documented calibration procedure tested on real substrate | [WI-PL-03](../plan/work-items/01-plant-science/WI-PL-03-watering-model.md), [WI-FW-05](../plan/work-items/02-firmware/WI-FW-05-irrigation-controller.md), [WI-FW-11](../plan/work-items/02-firmware/WI-FW-11-calibration-storage.md), [WI-QA-06](../plan/work-items/05-validation-qa/WI-QA-06-calibration-guide-test.md) |
| R4 | Water/electronics isolation failure | Medium | **Critical** | Mechanical + Electronics | Two-zone wet/dry bay; drip loops; leak tray; leak-triggered pump lockout; wet-run + electrical-safety verification | [WI-ME-03](../plan/work-items/04-mechanical/WI-ME-03-electronics-bay.md), [WI-ME-04](../plan/work-items/04-mechanical/WI-ME-04-wet-bay.md), [WI-FW-07](../plan/work-items/02-firmware/WI-FW-07-safety-state-machine.md), [WI-QA-02](../plan/work-items/05-validation-qa/WI-QA-02-wet-run-water-path.md), [WI-QA-08](../plan/work-items/05-validation-qa/WI-QA-08-electrical-safety.md) |
| R5 | Heat / noise from forcing a high-light fruiting crop into a compact frame | Medium | Medium | Mechanical + Electronics | LED thermal path + ventilation; quiet PWM fan with tach; thermal and acoustic verification against limits | [WI-ME-05](../plan/work-items/04-mechanical/WI-ME-05-light-mount.md), [WI-ME-06](../plan/work-items/04-mechanical/WI-ME-06-fan-mount.md), [WI-EE-06](../plan/work-items/03-electronics/WI-EE-06-trace-thermal-report.md), [WI-QA-03](../plan/work-items/05-validation-qa/WI-QA-03-thermal.md), [WI-QA-04](../plan/work-items/05-validation-qa/WI-QA-04-acoustic.md) |
| R6 | Excessive yield expectations from the compact 8–10 L baseline | Medium | Low | Documentation + Plant Science | Set realistic yield expectations in scope + grow guide; offer full-yield variant for higher yield | [WI-PS-04](../plan/work-items/00-project-setup/WI-PS-04-requirements-scope-lock.md), [WI-PL-01](../plan/work-items/01-plant-science/WI-PL-01-lifecycle-profile.md), [WI-DOC-06](../plan/work-items/06-documentation/WI-DOC-06-maintenance-grow-guide.md) |
| R7 | Scope creep (AI / app / display / enclosure) | High | Medium | Project & Repo | Locked scope doc with explicit non-goals; expansion features deferred to §4.3 headers / V2; change control via this register | [WI-PS-04](../plan/work-items/00-project-setup/WI-PS-04-requirements-scope-lock.md) (scope.md), [WI-PS-05](../plan/work-items/00-project-setup/WI-PS-05-risk-register.md) (this register) |
| R8 | Hardware safety verification (pump fail-off, leak lockout) blocked on the unbuilt firmware safety state machine | Medium | High | Firmware + Electronics | EE-08 board bring-up + HIL fault tests depend on [WI-FW-07](../plan/work-items/02-firmware/WI-FW-07-safety-state-machine.md) (currently *Not started*); these are the **in-hardware** proofs of pump fail-off (S6) and leak lockout (S5). Sequence FW-07 ahead of board fabrication so HIL is ready when silicon arrives; meanwhile the fixture can be built and dry-validated against the firmware sim / HAL mocks. The pump-fail-off hardware guarantee (gate pull-down) is already in the schematic and does not depend on firmware. | **Blocker:** [WI-FW-07](../plan/work-items/02-firmware/WI-FW-07-safety-state-machine.md); **blocked:** [WI-EE-08](../plan/work-items/03-electronics/WI-EE-08-bringup-hil.md); verified [WI-QA-05](../plan/work-items/05-validation-qa/WI-QA-05-fault-injection.md) |

---

## B. Safety risks (spec §17)

All §17 safety requirements are tracked here as risks, each with an owner and a mitigating work item.

### B.1 Water / electricity (§17.1)

| # | Risk | Likelihood | Impact | Owning track | Mitigation | Mitigating / verifying work item(s) |
|---|---|---|---|---|---|---|
| S1 | AC mains present inside the unit | Low | **Critical** | Electronics | External certified 24 VDC PSU only; no mains inside (locked) | [WI-PS-04](../plan/work-items/00-project-setup/WI-PS-04-requirements-scope-lock.md), [WI-EE-02](../plan/work-items/03-electronics/WI-EE-02-power-budget.md), verified [WI-QA-08](../plan/work-items/05-validation-qa/WI-QA-08-electrical-safety.md) |
| S2 | Electronics not isolated above the wet zone | Low | **Critical** | Mechanical | Upper dry bay isolated from lower wet bay | [WI-ME-03](../plan/work-items/04-mechanical/WI-ME-03-electronics-bay.md), verified [WI-QA-02](../plan/work-items/05-validation-qa/WI-QA-02-wet-run-water-path.md) |
| S3 | Cable run wicks water into electronics (no drip loops) | Medium | High | Mechanical | Drip loops on all cables; routed routing/clips | [WI-ME-07](../plan/work-items/04-mechanical/WI-ME-07-cable-tube-routing.md), verified [WI-QA-02](../plan/work-items/05-validation-qa/WI-QA-02-wet-run-water-path.md) |
| S4 | Reservoir overflows into electronics; no leak tray | Medium | **Critical** | Mechanical | Leak tray below water system; reservoir cannot overflow toward electronics | [WI-ME-04](../plan/work-items/04-mechanical/WI-ME-04-wet-bay.md), verified [WI-QA-02](../plan/work-items/05-validation-qa/WI-QA-02-wet-run-water-path.md) |
| S5 | Leak not detected / pump not locked out on leak | Medium | **Critical** | Firmware | Leak detection drives immediate pump lockout in the safety state machine | [WI-FW-07](../plan/work-items/02-firmware/WI-FW-07-safety-state-machine.md), verified [WI-QA-05](../plan/work-items/05-validation-qa/WI-QA-05-fault-injection.md) |
| S6 | Pump keeps running after MCU reset / brownout | Medium | High | Firmware | Pump output fails **off** on reset/brownout; watchdog/brownout enabled | [WI-FW-07](../plan/work-items/02-firmware/WI-FW-07-safety-state-machine.md), verified by HIL [WI-EE-08](../plan/work-items/03-electronics/WI-EE-08-bringup-hil.md) + [WI-QA-05](../plan/work-items/05-validation-qa/WI-QA-05-fault-injection.md) |
| S7 | Pump floods due to no daily/runtime max | Medium | High | Firmware | Daily-max and runtime-max limits enforced in irrigation + safety logic | [WI-FW-05](../plan/work-items/02-firmware/WI-FW-05-irrigation-controller.md), [WI-FW-07](../plan/work-items/02-firmware/WI-FW-07-safety-state-machine.md), verified [WI-QA-05](../plan/work-items/05-validation-qa/WI-QA-05-fault-injection.md) |
| S8 | Connectors not rated/keyed; no strain relief | Low | Medium | Electronics | Locking, keyed, labeled low-voltage connectors; strain relief | [WI-EE-05](../plan/work-items/03-electronics/WI-EE-05-harness-pinout.md), verified [WI-EE-08](../plan/work-items/03-electronics/WI-EE-08-bringup-hil.md) |
| S9 | Voltage rails unlabeled | Low | Medium | Electronics | Label voltage rails on board and harness | [WI-EE-03](../plan/work-items/03-electronics/WI-EE-03-schematic.md), [WI-EE-05](../plan/work-items/03-electronics/WI-EE-05-harness-pinout.md) |

### B.2 Thermal (§17.2)

| # | Risk | Likelihood | Impact | Owning track | Mitigation | Mitigating / verifying work item(s) |
|---|---|---|---|---|---|---|
| S10 | LED thermal path not validated → overheating | Medium | High | Electronics + Mechanical | Validate LED thermal path and mounting; thermal report | [WI-EE-06](../plan/work-items/03-electronics/WI-EE-06-trace-thermal-report.md), [WI-ME-05](../plan/work-items/04-mechanical/WI-ME-05-light-mount.md), verified [WI-QA-03](../plan/work-items/05-validation-qa/WI-QA-03-thermal.md) |
| S11 | LED does not derate/shut down on high temperature | Medium | High | Firmware | Firmware derates or shuts down LED on canopy/driver over-temp | [WI-FW-04](../plan/work-items/02-firmware/WI-FW-04-light-controller.md), [WI-FW-07](../plan/work-items/02-firmware/WI-FW-07-safety-state-machine.md), verified [WI-QA-05](../plan/work-items/05-validation-qa/WI-QA-05-fault-injection.md) |
| S12 | Printed material near LED heat degrades; combustible touching heatsink | Medium | High | Mechanical | Heat-tolerant material near LED (PETG/ASA/ABS); no combustible touching heatsink; clearance | [WI-ME-05](../plan/work-items/04-mechanical/WI-ME-05-light-mount.md), verified [WI-QA-03](../plan/work-items/05-validation-qa/WI-QA-03-thermal.md) |
| S13 | LED driver mounted without ventilation | Low | Medium | Mechanical + Electronics | Driver mounted with ventilation in dry bay | [WI-ME-03](../plan/work-items/04-mechanical/WI-ME-03-electronics-bay.md), [WI-EE-06](../plan/work-items/03-electronics/WI-EE-06-trace-thermal-report.md) |
| S14 | Fan failure not detected | Medium | Medium | Firmware | Fan tach monitored; fault on stall feeds climate/safety logic | [WI-FW-06](../plan/work-items/02-firmware/WI-FW-06-climate-controller.md), [WI-FW-07](../plan/work-items/02-firmware/WI-FW-07-safety-state-machine.md), verified [WI-QA-05](../plan/work-items/05-validation-qa/WI-QA-05-fault-injection.md) |

### B.3 Food / contact (§17.3)

| # | Risk | Likelihood | Impact | Owning track | Mitigation | Mitigating / verifying work item(s) |
|---|---|---|---|---|---|---|
| S15 | Unknown/leaching plastics in reservoir | Low | Medium | Mechanical | Food-/aquarium-safe reservoir and tubing materials; no leaching materials | [WI-ME-04](../plan/work-items/04-mechanical/WI-ME-04-wet-bay.md), documented [WI-DOC-02](../plan/work-items/06-documentation/WI-DOC-02-safety.md) |
| S16 | Reservoir not cleanable; contaminants reach water | Low | Medium | Mechanical | Removable, cleanable reservoir; keep electronics contaminants away from water | [WI-ME-02](../plan/work-items/04-mechanical/WI-ME-02-pot-reservoir-fit.md), [WI-ME-04](../plan/work-items/04-mechanical/WI-ME-04-wet-bay.md) |
| S17 | Users assume the unit is certified for food production | Medium | Low | Documentation | Document explicitly: DIY, not certified for commercial food production | [WI-DOC-02](../plan/work-items/06-documentation/WI-DOC-02-safety.md) |

### B.4 Child / pet (§17.4)

| # | Risk | Likelihood | Impact | Owning track | Mitigation | Mitigating / verifying work item(s) |
|---|---|---|---|---|---|---|
| S18 | Exposed fan blades (no guard) | Low | High | Mechanical | Fan guard required | [WI-ME-06](../plan/work-items/04-mechanical/WI-ME-06-fan-mount.md) |
| S19 | Exposed sharp metal edges | Low | Medium | Mechanical | No exposed sharp metal; deburr/cover; verified at alpha build | [WI-ME-01](../plan/work-items/04-mechanical/WI-ME-01-assembly-cad.md), [WI-ME-08](../plan/work-items/04-mechanical/WI-ME-08-tolerance-alpha-build.md) |
| S20 | Access to pump impeller | Low | Medium | Mechanical | No easy access to pump impeller; removable pump filter/guard | [WI-ME-04](../plan/work-items/04-mechanical/WI-ME-04-wet-bay.md) |
| S21 | Reservoir lid not secure | Low | Medium | Mechanical | Secure reservoir lid | [WI-ME-04](../plan/work-items/04-mechanical/WI-ME-04-wet-bay.md) |
| S22 | Capsaicin exposure — the plant is a superhot pepper | Medium | Medium | Documentation | Warning about capsaicin, pets, children, and safe handling in safety + grow guide | [WI-DOC-02](../plan/work-items/06-documentation/WI-DOC-02-safety.md), [WI-DOC-06](../plan/work-items/06-documentation/WI-DOC-06-maintenance-grow-guide.md) |

---

## C. Redesign risks (ECO-003 — two-pillar, top electronics, passive watering)

| # | Risk | Likelihood | Impact | Owning track | Mitigation | Mitigating / verifying work item(s) |
|---|---|---|---|---|---|---|
| R9 | Passive watering underperforms for a mature pepper (insufficient wick rate / effective media) | Medium | High | Plant Science + Mechanical | Size wick area + reservoir contact; ~5 L raised insert + 6 L reservoir; **validate in the n=2 grow trial**; reserve space for an optional pump/aeration retrofit if passive is inadequate | [WI-PL-03](../plan/work-items/01-plant-science/WI-PL-03-watering-model.md), [WI-ME-04](../plan/work-items/04-mechanical/WI-ME-04-wet-bay.md), verified [WI-QA-07](../plan/work-items/05-validation-qa/WI-QA-07-grow-trial.md) |
| R10 | Roots waterlogged / no oxygen (passive semi-hydro) | Medium | High | Plant Science | Maintain an air gap; slotted insert + perforated floor + capillary media; no fully-submerged root mass | [WI-PL-03](../plan/work-items/01-plant-science/WI-PL-03-watering-model.md), verified [WI-QA-07](../plan/work-items/05-validation-qa/WI-QA-07-grow-trial.md) |
| R11 | Reservoir stagnation (no circulation) | Low | Medium | Plant Science + Docs | Inert nutrients; opaque tank; documented refill/clean cadence; avoid organic sludge | [WI-PL-03](../plan/work-items/01-plant-science/WI-PL-03-watering-model.md), [WI-DOC-06](../plan/work-items/06-documentation/WI-DOC-06-maintenance-grow-guide.md) |
| R12 | USB-C power insufficient for the 50–80 W LED | Medium | High | Electronics | Validate USB-C PD negotiation + cable/connector rating + driver input; **reserve a DC-barrel fallback** if PD is inadequate (mechanical reserves connector space only) | Electronics (power budget / schematic); flagged in [ECO-003](ECO-003-v1-redesign.md) §3 |
| R13 | Pillar joints wobble (two-pillar structure under the cantilevered light + plant load) | Medium | Medium | Mechanical | Pillar sockets (30 mm) + underside M4 into inserts + anti-rotation dowel + block set screws; validate with a load test (physics sim deferred) | [WI-ME-01](../plan/work-items/04-mechanical/WI-ME-01-assembly-cad.md), [WI-ME-08](../plan/work-items/04-mechanical/WI-ME-08-tolerance-alpha-build.md) |
| R14 | Effective media (~5 L raised insert) too small vs the old 10 L pot → reduced vigour/yield | Medium | Medium | Plant Science + Mechanical + Docs | Documented trade-off; size insert as large as the low base allows; set realistic yield expectations; grow-trial-gated | [WI-ME-02](../plan/work-items/04-mechanical/WI-ME-02-pot-reservoir-fit.md), [WI-PL-01](../plan/work-items/01-plant-science/WI-PL-01-lifecycle-profile.md), verified [WI-QA-07](../plan/work-items/05-validation-qa/WI-QA-07-grow-trial.md) |

---

## Change log

| Date | Change | Reference |
|---|---|---|
| 2026-06-14 | **ECO-003 (V1 redesign):** two-pillar form; **electronics moved to the top block**; **pump removed → passive self-watering**; reservoir 4 L→6 L; pot→integrated insert; status LEDs 5→4; power→USB-C; wet/dry separation now top/bottom. Retires/changes R3, R4, R5, R8, S2, S5, S6, S7, S14, S18, S20; adds R9–R14. Maintainer (Project & Repo) approved. | [ECO-003](ECO-003-v1-redesign.md) |
| 2026-06-13 | Register seeded with §22 engineering risks (R1–R7) and §17 safety risks (S1–S22). | WI-PS-05 |
| 2026-06-13 | Design review (spec §23): pump current-sense made required (DR-04) and battery-backed RTC added (DR-05); pre-order modeling + bench-characterization + surrogate-shakedown gates added (DR-01/02/03). | spec §23 |
| 2026-06-13 | Grow-trial decision: run **n=2 parallel units** (DR-03) — no single-unit-trial risk accepted. | spec §23 DR-03, WI-QA-07/10 |
| 2026-06-13 | Recorded R8: EE-08 bring-up/HIL (in-hardware pump fail-off + leak lockout proofs) is blocked on the unbuilt WI-FW-07 safety state machine. | R8, WI-EE-08, WI-FW-07 |

> To change a locked requirement or reopen a non-goal, add a row here describing the change, its risk
> impact, and the approving track before the change takes effect.

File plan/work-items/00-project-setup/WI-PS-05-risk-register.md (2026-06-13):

# WI-PS-05 — Risk register

| Field | Value |
|---|---|
| Track | Project & Repo |
| Milestone | M0-06 |
| Depends on | WI-PS-04 |
| Spec refs | §22 (key risks), §17 (safety) |
| Status | Done |

## Objective

Track the engineering and safety risks the spec calls out, with owners and mitigations.

## Deliverables

- [x] `docs/risk-register.md` seeded with the seven §22 risks:
  1. Underpowered / poorly specified light.
  2. Too-small pot (root volume).
  3. Overwatering from bad moisture calibration.
  4. Water/electronics isolation failure.
  5. Heat/noise from forcing a high-light crop into a compact frame.
  6. Excessive yield expectations from the 8–10 L baseline.
  7. Scope creep (AI/app/display/enclosure).
- [x] Each risk has: likelihood, impact, owning track, mitigation, and the work item that closes it.

## Acceptance criteria

- All §22 risks and all §17 safety risks appear with an owner and a linked mitigating work item.

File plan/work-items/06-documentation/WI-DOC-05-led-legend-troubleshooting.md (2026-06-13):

# WI-DOC-05 — LED status legend & troubleshooting

| Field | Value |
|---|---|
| Track | Documentation |
| Milestone | (release) |
| Depends on | WI-FW-08 |
| Spec refs | §3.5, §9.8, §14.3 |
| Status | Not started |

## Objective

Write the LED status legend (the primary UI) and a troubleshooting guide keyed to the indicators.

## Deliverables

- [ ] `docs/led-status-legend.md`: each of the 5 LEDs × green/amber/red × blink pattern → meaning (§9.8).
- [ ] Colorblind-safe explanation (position + pattern, not color alone).
- [ ] `docs/troubleshooting.md` mapping each fault LED to likely cause + user action.

## Acceptance criteria

- LED status legend complete (§21) and matches the firmware mapping in [WI-FW-08](../02-firmware/WI-FW-08-led-status.md).

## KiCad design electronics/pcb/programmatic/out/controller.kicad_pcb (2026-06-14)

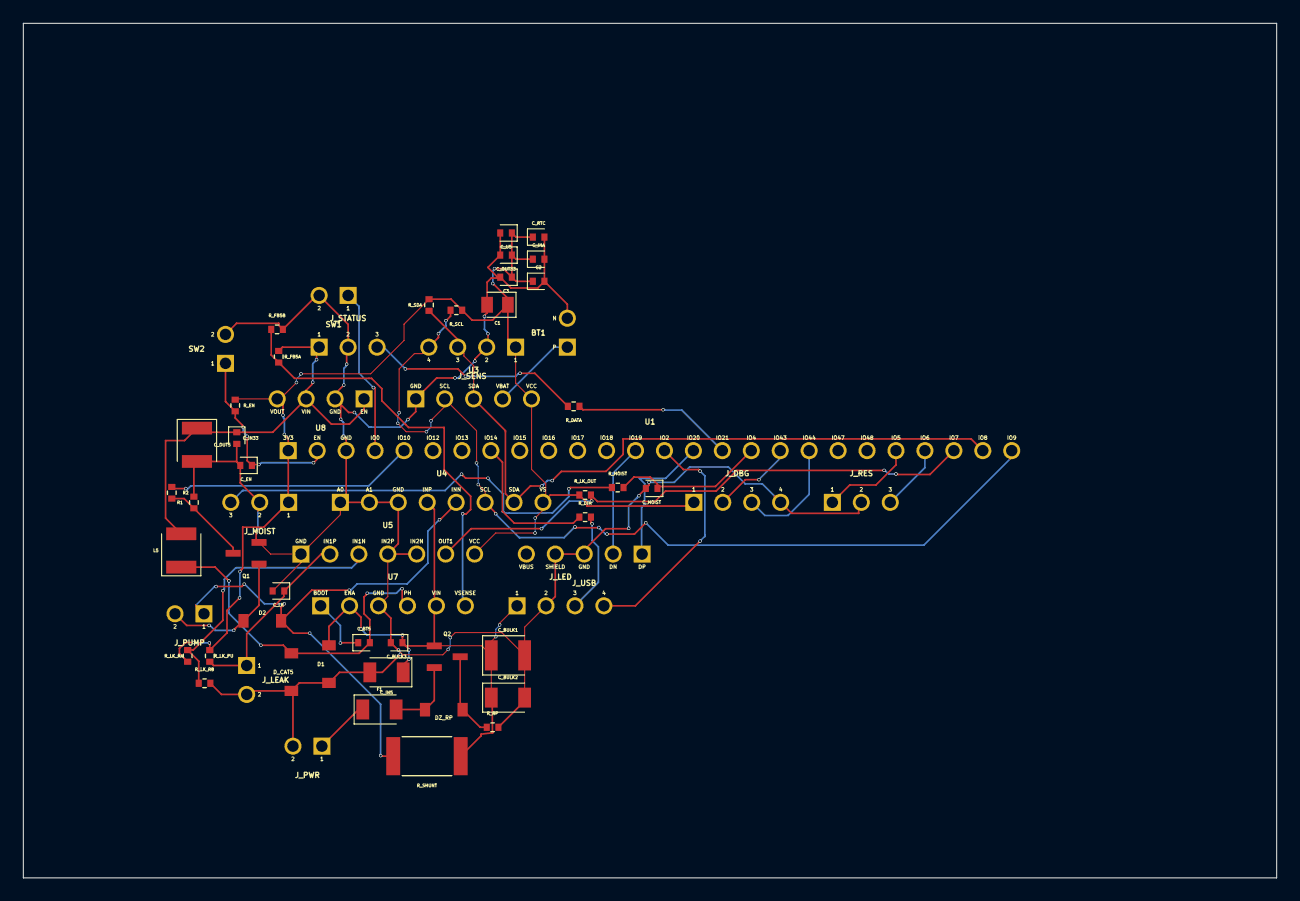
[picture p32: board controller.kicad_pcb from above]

Board: 2 copper layers, 110.0 x 75.0 mm, 60 parts (0 on the bottom side), 35 nets.

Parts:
BT1: chip_pinrow2
C1: 22uF; capacitor_0805
C2, C3: 100nF; capacitor_0402
C_BT5: 10nF; capacitor_0402
C_BULK1: 100uF; capacitor_1210
C_BULK2: 10uF; capacitor_1206
C_BULK3: 100nF; capacitor_0402
C_EN: 100nF; capacitor_0402
C_IN5: 10uF; capacitor_1206
C_IN33: 1uF; capacitor_0402
C_INA: 100nF; capacitor_0402
C_LK: 100nF; capacitor_0402
C_MOIST: 10nF; capacitor_0402
C_OUT5: 22uF; capacitor_1210
C_OUT33: 1uF; capacitor_0402
C_RTC: 100nF; capacitor_0402
C_U5: 100nF; capacitor_0402
D1, D2: D; diode_sod123
DZ_RP: D; diode_sod123
D_CAT5: D; diode_sod123
F1: F1; fuse_1206
J_DBG: chip_pinrow4
J_LEAK: chip_pinrow2
J_LED: chip_pinrow4
J_MOIST: chip_pinrow3
J_PUMP: chip_pinrow2
J_PWR: chip_pinrow2
J_RES: chip_pinrow3
J_SENS: chip_pinrow4
J_STATUS: chip_pinrow3
J_USB: chip_pinrow5
L5: 10H; inductor_1210
Q1: Q1; mosfet_sot23
Q2: Q2; mosfet_sot23
R1: 10kΩ; resistor_res0402
R2: 100Ω; resistor_res0402
R_DATA: 330Ω; resistor_res0402
R_DIM: 100Ω; resistor_res0402
R_EN: 10kΩ; resistor_res0402
R_FB5A: 22kΩ; resistor_res0402
R_FB5B: 7.15kΩ; resistor_res0402
R_LK_OUT: 10kΩ; resistor_res0402
R_LK_PU: 100kΩ; resistor_res0402
R_LK_RA: 10kΩ; resistor_res0402
R_LK_RB: 10kΩ; resistor_res0402
R_MOIST: 1kΩ; resistor_res0402
R_RP: 100kΩ; resistor_res0402
R_SCL: 4.7kΩ; resistor_res0402
R_SDA: 4.7kΩ; resistor_res0402
R_SHUNT: 100mΩ; resistor_res2512
SW1, SW2: chip_pinrow2
U1: chip_pinrow26
U3: chip_pinrow5
U4: chip_pinrow8
U5: chip_pinrow7
U7: chip_pinrow6
U8: chip_pinrow4

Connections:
BOOT5: C_BT5.1, U7.1
EN: C_EN.1, R_EN.2, SW2.1, U1.2
FB5: R_FB5A.2, R_FB5B.1, U7.6
GND: BT1.2, C1.2, C2.2, C3.2, C_BULK1.2, C_BULK2.2, C_BULK3.2, C_EN.2, C_IN5.2, C_IN33.2, C_INA.2, C_LK.2, C_MOIST.2, C_OUT5.2, C_OUT33.2, C_RTC.2, C_U5.2, D1.1, D_CAT5.1, J_DBG.4, J_LEAK.2, J_LED.2, J_MOIST.2, J_PWR.2, J_RES.2, J_SENS.2, J_STATUS.2, J_USB.3, J_USB.4, Q1.2, R1.2, R_FB5B.2, R_LK_RB.2, R_RP.2, SW1.2, SW2.2, U1.3, U3.1, U4.1, U4.2, U4.3, U5.1, U5.4, U5.5, U7.3, U8.2
IO0_BOOT: SW1.1, U1.4
LEAK_DET: R_LK_OUT.2, U1.24, U5.6
LEAK_REF: R_LK_RA.2, R_LK_RB.1, U5.3
LEAK_SENSE: C_LK.1, J_LEAK.1, R_LK_PU.2, U5.2
LED_DIM: R_DIM.1, U1.8
LED_DIM_OUT: J_LED.3, R_DIM.2
LED_NTC: J_LED.4, U1.14
MOIST_ADC: C_MOIST.1, R_MOIST.2, U1.17
MOIST_SIG: J_MOIST.3, R_MOIST.1
P3V3: C1.1, C2.1, C3.1, C_INA.1, C_OUT33.1, C_RTC.1, C_U5.1, J_DBG.1, J_MOIST.1, J_SENS.1, R_EN.1, R_LK_OUT.1, R_LK_PU.1, R_LK_RA.1, R_SCL.1, R_SDA.1, U1.1, U3.5, U4.8, U5.7, U8.4
P5V: C_IN33.1, C_OUT5.1, J_STATUS.1, L5.2, R_FB5A.1, U8.1, U8.3
P24V: C_BULK1.1, C_BULK2.1, C_BULK3.1, C_IN5.1, D1.2, J_LED.1, Q2.1, R_SHUNT.1, U4.4, U7.2, U7.5
P24V_FUSED: DZ_RP.2, F1.2, Q2.2
P24V_IN: F1.1, J_PWR.1
PH5: C_BT5.2, D_CAT5.2, L5.1, U7.4
PUMP_GATE: Q1.3, R1.1, R2.2
PUMP_P: D2.2, J_PUMP.1, R_SHUNT.2, U4.5
PUMP_PWM: R2.1, U1.5
PUMP_RET: D2.1, J_PUMP.2, Q1.1
RES_LEVEL_ADC: J_RES.3, U1.23
RES_LOW_SW: J_RES.1, U1.22
RP_GATE: DZ_RP.1, Q2.3, R_RP.1
SCL: J_SENS.4, R_SCL.2, U1.26, U3.2, U4.6
SDA: J_SENS.3, R_SDA.2, U1.25, U3.3, U4.7
STATUS_DATA: R_DATA.1, U1.16
STATUS_DATA_OUT: J_STATUS.3, R_DATA.2
UART_RX: J_DBG.3, U1.19
UART_TX: J_DBG.2, U1.18
USB_DM: J_USB.2, U1.13
USB_DP: J_USB.1, U1.15
VBAT: BT1.1, U3.4

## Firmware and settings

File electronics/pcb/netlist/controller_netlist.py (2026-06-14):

#!/usr/bin/env python3
# SPDX-License-Identifier: CERN-OHL-S-2.0
"""
controller_netlist.py — the OpenCanopy controller board's electrical design, as data.

This is the **single source of truth for the schematic** (WI-EE-03) at component + connectivity
level: every populated part, every net, pin by pin. It exists because the project has no KiCad GUI in
this environment — so the schematic is captured here as a reviewable, diff-able, CI-checkable netlist
instead of a binary `.kicad_sch`. From it we emit:

  * a flat netlist CSV (`--emit-csv`)            -> human/diff-friendly
  * a KiCad-importable netlist  (`--emit-kicad`)  -> `kicad-cli`/"Import Netlist" drives PCB layout

and we run an **ERC-style design-rule check** (`--check` / `--selftest`) that stands in for
`kicad-cli sch erc` until the KiCad source is entered (then ERC supersedes it). The check also
cross-validates the netlist against the committed pin map and the BOM, so the firmware pin contract
(`electronics/analysis/pin-map.csv`) and the buildable parts list (`electronics/bom/bom.csv`) can
never silently drift from the schematic.

Pin identifiers are **functional names** (e.g. `IO8`, `VIN`, `GND`, `IN+`), not datasheet pad numbers
— unambiguous, reviewable, and library-independent (KiCad maps symbol pin names on import). Two-pin
passives use `1`/`2`. Net names follow KiCad power convention (`GND`, `+3V3`, `+5V`, `+12V`, `+24V`).

No fan in V1 (ECO-001): the fan-drive parts are present as **DNP** so the board can drive a fan later
without a respin; their nets are flagged `reserved` and excluded from the floating-net rule.

Run:  python3 electronics/pcb/netlist/controller_netlist.py --selftest
"""
from __future__ import annotations

import argparse
import csv
import sys
from pathlib import Path

HERE = Path(__file__).resolve().parent
REPO = HERE.parents[2]
PIN_MAP = REPO / "electronics" / "analysis" / "pin-map.csv"
BOM = REPO / "electronics" / "bom" / "bom.csv"

# ----------------------------------------------------------------------------- components
# ref -> (value, footprint-class, part_no, board, populated)
#   board:     "ctrl" controller PCB / "status" front-panel PCB
#   populated: True = fitted in V1 / False = DNP (footprint only)
P = True
DNP = False


class Comp:
    __slots__ = ("value", "footprint", "part", "board", "populated", "desc")

    def __init__(self, value, footprint, part, board="ctrl", populated=P, desc=""):
        self.value = value
        self.footprint = footprint
        self.part = part
        self.board = board
        self.populated = populated
        self.desc = desc


COMPONENTS: dict[str, Comp] = {
    # --- MCU + support ---
    "U1": Comp("ESP32-S3-WROOM-1", "RF_Module:ESP32-S3-WROOM-1", "ESP32-S3-WROOM-1-N8R8", desc="MCU module"),
    "C1": Comp("22uF", "C_0805", "GRM21-22uF-10V", desc="U1 3V3 bulk"),
    "C2": Comp("100nF", "C_0402", "C-100nF", desc="U1 decoupling"),
    "C3": Comp("100nF", "C_0402", "C-100nF", desc="U1 decoupling"),
    "R_EN": Comp("10k", "R_0402", "R-10k", desc="U1 EN pull-up"),
    "C_EN": Comp("100nF", "C_0402", "C-100nF", desc="U1 EN RC delay"),
    "SW1": Comp("BOOT", "SW_SPST_SMD", "SW-TACT", desc="boot/download button (IO0)"),
    "SW2": Comp("RST", "SW_SPST_SMD", "SW-TACT", desc="chip reset (EN)"),
    # --- I2C bus pull-ups ---
    "R_SDA": Comp("4.7k", "R_0402", "R-4k7", desc="I2C SDA pull-up to 3V3"),
    "R_SCL": Comp("4.7k", "R_0402", "R-4k7", desc="I2C SCL pull-up to 3V3"),
    # --- RTC (battery-backed) ---
    "U3": Comp("DS3231SN", "SOIC-16W", "DS3231SN", desc="RTC, I2C 0x68"),
    "C_RTC": Comp("100nF", "C_0402", "C-100nF", desc="U3 decoupling"),
    "BT1": Comp("CR2032", "BatteryHolder_CR2032", "CR2032+holder", desc="RTC backup cell"),
    # --- Pump current monitor ---
    "U4": Comp("INA219", "SOIC-8", "INA219AIDR", desc="pump current monitor, I2C 0x40"),
    "C_INA": Comp("100nF", "C_0402", "C-100nF", desc="U4 decoupling"),
    "R_SHUNT": Comp("0.1R", "R_2512", "R-0R1-1W", desc="pump current shunt (0.1 ohm)"),
    # --- Leak comparator ---
    "U5": Comp("LM393", "SOIC-8", "LM393DR", desc="leak comparator (dual; one used)"),
    "C_U5": Comp("100nF", "C_0402", "C-100nF", desc="U5 decoupling"),
    "R_LK_PU": Comp("100k", "R_0402", "R-100k", desc="leak-trace pull-up to 3V3"),
    "R_LK_RA": Comp("10k", "R_0402", "R-10k", desc="leak threshold divider top"),
    "R_LK_RB": Comp("10k", "R_0402", "R-10k", desc="leak threshold divider bottom"),
    "R_LK_OUT": Comp("10k", "R_0402", "R-10k", desc="LM393 open-collector pull-up"),
    "C_LK": Comp("100nF", "C_0402", "C-100nF", desc="leak debounce"),
    # --- Moisture front end ---
    "R_MOIST": Comp("1k", "R_0402", "R-1k", desc="moisture ADC series R"),
    "C_MOIST": Comp("10nF", "C_0402", "C-10nF", desc="moisture ADC RC filter"),
    # --- LED-heatsink NTC divider (optional, DR-09 secondary) ---
    "R_NTC": Comp("10k", "R_0402", "R-10k", populated=DNP, desc="NTC divider top (optional)"),
    # --- Power input + protection ---
    "F1": Comp("6.3A", "Fuseholder_5x20", "fuse-6p3A", desc="input fuse (8A for 150W build)"),
    "Q2": Comp("DMP3056L", "SOT-23", "DMP3056L", desc="reverse-polarity P-FET (high-side)"),
    "R_RP": Comp("100k", "R_0402", "R-100k", desc="Q2 gate resistor to GND"),
    "DZ_RP": Comp("15V", "SOD-323", "BZT52-15V", desc="Q2 gate clamp Zener"),
    "D1": Comp("SMBJ28A", "SMB", "SMBJ28A", desc="input TVS (28V standoff)"),
    "C_BULK1": Comp("100uF", "CP_Elec_8x10", "100uF-50V", desc="24V bulk electrolytic"),
    "C_BULK2": Comp("10uF", "C_1206", "10uF-50V", desc="24V bulk ceramic"),
    "C_BULK3": Comp("100nF", "C_0402", "C-100nF", desc="24V HF bypass"),
    # --- 24->12V buck (optional/DNP: 12V pump alternate only; no fan in V1) ---
    "U6": Comp("TPS5430", "SOIC-8", "TPS5430DDA", populated=DNP, desc="24->12V buck (optional)"),
    "C_IN12": Comp("10uF", "C_1206", "10uF-50V", populated=DNP, desc="U6 input cap"),
    "C_BT12": Comp("10nF", "C_0402", "C-10nF", populated=DNP, desc="U6 boot cap"),
    "L12": Comp("15uH", "L_12x12", "15uH-3A", populated=DNP, desc="U6 inductor"),
    "D_CAT12": Comp("B340A", "SMC", "B340A", populated=DNP, desc="U6 catch diode"),
    "C_OUT12": Comp("22uF", "C_1210", "22uF-25V", populated=DNP, desc="U6 output cap"),
    "R_FB12A": Comp("68k", "R_0402", "R-68k", populated=DNP, desc="U6 feedback top"),
    "R_FB12B": Comp("7.5k", "R_0402", "R-7k5", populated=DNP, desc="U6 feedback bottom"),
    # --- 24->5V buck ---
    "U7": Comp("TPS5430", "SOIC-8", "TPS5430DDA", desc="24->5V buck"),
    "C_IN5": Comp("10uF", "C_1206", "10uF-50V", desc="U7 input cap"),
    "C_BT5": Comp("10nF", "C_0402", "C-10nF", desc="U7 boot cap"),
    "L5": Comp("10uH", "L_12x12", "10uH-3A", desc="U7 inductor"),
    "D_CAT5": Comp("B340A", "SMC", "B340A", desc="U7 catch diode"),
    "C_OUT5": Comp("22uF", "C_1210", "22uF-25V", desc="U7 output cap"),
    "R_FB5A": Comp("22k", "R_0402", "R-22k", desc="U7 feedback top"),
    "R_FB5B": Comp("7.15k", "R_0402", "R-7k15", desc="U7 feedback bottom"),
    # --- 5->3.3V LDO ---
    "U8": Comp("AP2112K-3.3", "SOT-23-5", "AP2112K-3.3", desc="3V3 LDO for MCU/logic"),
    "C_IN33": Comp("1uF", "C_0402", "C-1uF", desc="U8 input cap"),
    "C_OUT33": Comp("1uF", "C_0402", "C-1uF", desc="U8 output cap"),
    # --- Pump drive (fail-OFF) ---
    "Q1": Comp("DMN3404L", "SOT-23", "DMN3404L", desc="pump N-FET, low-side"),
    "R1": Comp("10k", "R_0402", "R-10k", desc="pump gate->GND pull-down (FAIL-OFF)"),
    "R2": Comp("100R", "R_0402", "R-100R", desc="pump gate series R"),
    "D2": Comp("SS34", "SMC", "SS34", desc="pump flyback Schottky"),
    # --- LED dim (PWM-direct populated; 0-10V op-amp path DNP) ---
    "R_DIM": Comp("100R", "R_0402", "R-100R", desc="LED dim series R"),
    "U9": Comp("MCP6001", "SOT-23-5", "MCP6001", populated=DNP, desc="0-10V dim buffer (optional)"),
    "R_DIMF": Comp("10k", "R_0402", "R-10k", populated=DNP, desc="dim RC filter R (optional)"),
    "C_DIMF": Comp("1uF", "C_0402", "C-1uF", populated=DNP, desc="dim RC filter C (optional)"),
    # --- Fan drive (DNP: no fan in V1, ECO-001) — 4-pin PWM fan provision (PWM in + tach out) ---
    "R_FANG": Comp("100R", "R_0402", "R-100R", populated=DNP, desc="fan PWM series R (DNP)"),
    "R_TACH": Comp("10k", "R_0402", "R-10k", populated=DNP, desc="fan tach pull-up (DNP)"),
    # --- Status data series R (on controller side of J_STATUS) ---
    "R_DATA": Comp("330R", "R_0402", "R-330R", desc="WS2812 data series R"),
    # --- Field connectors ---
    "J_PWR": Comp("XT30", "XT30PW", "XT30PW", desc="24V power input"),
    "J_LED": Comp("JST_VH_4", "JST_VH_B4PS", "B4PS-VH", desc="grow light (24V/GND/DIM/NTC)"),
    "J_PUMP": Comp("JST_VH_2", "JST_VH_B2PS", "B2PS-VH", desc="pump (24V/return)"),
    "J_FAN": Comp("FAN_4", "Fan_4pin", "47053-1000", populated=DNP, desc="fan header (DNP, no fan V1)"),
    "J_MOIST": Comp("JST_PH_3", "JST_PH_B3B", "B3B-PH", desc="moisture probe"),
    "J_RES": Comp("JST_PH_3", "JST_PH_B3B", "B3B-PH", desc="reservoir level"),
    "J_LEAK": Comp("JST_PH_2", "JST_PH_B2B", "B2B-PH", desc="leak sensor"),
    "J_SENS": Comp("JST_PH_4", "JST_PH_B4B", "B4B-PH", desc="temp/RH (SHT40) + I2C"),
    "J_STATUS": Comp("JST_XH_3", "JST_XH_B3B", "B3B-XH", desc="status LED board"),
    "J_DBG": Comp("Header_4", "PinHeader_1x04", "header-4", desc="debug UART"),
    "J_USB": Comp("USB-C", "USB_C_Receptacle", "USB4105", desc="USB-CDC flash/log"),
    "J_EXP": Comp("Header_6", "PinHeader_1x06", "header-6", populated=DNP, desc="expansion (HX711/PAR/pH-EC)"),
    "J_CAM": Comp("Header_2", "PinHeader_1x02", "header-2", populated=DNP, desc="camera (unpopulated)"),
    # --- Status LED board (separate PCB2) ---
    "LED1": Comp("WS2812B-2020", "LED_WS2812B-2020", "WS2812B-2020", board="status", desc="status pos 1"),
    "LED2": Comp("WS2812B-2020", "LED_WS2812B-2020", "WS2812B-2020", board="status", desc="status pos 2"),
    "LED3": Comp("WS2812B-2020", "LED_WS2812B-2020", "WS2812B-2020", board="status", desc="status pos 3"),
    "LED4": Comp("WS2812B-2020", "LED_WS2812B-2020", "WS2812B-2020", board="status", desc="status pos 4"),
    "LED5": Comp("WS2812B-2020", "LED_WS2812B-2020", "WS2812B-2020", board="status", desc="status pos 5"),
    "C_L1": Comp("100nF", "C_0402", "C-100nF", board="status", desc="LED1 decoupling"),
    "C_L2": Comp("100nF", "C_0402", "C-100nF", board="status", desc="LED2 decoupling"),
    "C_L3": Comp("100nF", "C_0402", "C-100nF", board="status", desc="LED3 decoupling"),
    "C_L4": Comp("100nF", "C_0402", "C-100nF", board="status", desc="LED4 decoupling"),
    "C_L5": Comp("100nF", "C_0402", "C-100nF", board="status", desc="LED5 decoupling"),
    "C_LBULK": Comp("10uF", "C_0805", "10uF-10V", board="status", desc="status board bulk"),
    "D_LVD": Comp("1N5817", "SOD-123", "1N5817", board="status", desc="series diode: drop 5V->~4.5V for WS2812 VIH"),
    "J_STA": Comp("JST_XH_3", "JST_XH_B3B", "B3B-XH", board="status", desc="cable from controller"),
}

# ----------------------------------------------------------------------------- nets
# net -> list of "REF.PIN".  Functional pin names.  KiCad power-net naming.
NETS: dict[str, list[str]] = {
    # ---------- controller board ----------
    # Power input chain: J_PWR -> F1 -> Q2 (reverse-pol) -> +24V protected rail
    "+24V_IN": ["J_PWR.1", "F1.1"],
    "+24V_FUSED": ["F1.2", "Q2.S", "DZ_RP.K"],
    "RP_GATE": ["Q2.G", "DZ_RP.A", "R_RP.1"],
    "+24V": [
        "Q2.D", "D1.K", "C_BULK1.+", "C_BULK2.1", "C_BULK3.1",
        "U6.VIN", "U6.ENA", "C_IN12.1", "U7.VIN", "U7.ENA", "C_IN5.1",
        "J_LED.1", "R_SHUNT.1", "U4.IN+",
    ],
    # Pump high-side current shunt then connector then low-side FET to GND
    "PUMP_+": ["R_SHUNT.2", "U4.IN-", "J_PUMP.1", "D2.K"],
    "PUMP_RET": ["J_PUMP.2", "Q1.D", "D2.A"],
    "PUMP_GATE": ["Q1.G", "R2.2", "R1.1"],
    # 12V buck (DNP / optional 12V pump)
    "PH12": ["U6.PH", "L12.1", "D_CAT12.K", "C_BT12.2"],
    "+12V": ["L12.2", "C_OUT12.1", "R_FB12A.1", "J_FAN.2"],
    "FB12": ["U6.VSENSE", "R_FB12A.2", "R_FB12B.1"],
    "BOOT12": ["U6.BOOT", "C_BT12.1"],
    # 5V buck
    "PH5": ["U7.PH", "L5.1", "D_CAT5.K", "C_BT5.2"],
    "+5V": ["L5.2", "C_OUT5.1", "R_FB5A.1", "U8.VIN", "U8.EN", "C_IN33.1", "J_STATUS.1"],
    "FB5": ["U7.VSENSE", "R_FB5A.2", "R_FB5B.1"],
    "BOOT5": ["U7.BOOT", "C_BT5.1"],
    # 3V3 LDO
    "+3V3": [
        "U8.VOUT", "C_OUT33.1",
        "U1.3V3", "C1.1", "C2.1", "C3.1", "R_EN.1",
        "R_SDA.1", "R_SCL.1",
        "U3.VCC", "C_RTC.1",
        "U4.VS", "C_INA.1",
        "U5.VCC", "C_U5.1", "R_LK_PU.1", "R_LK_RA.1", "R_LK_OUT.1",
        "R_NTC.1", "R_TACH.2",
        "J_MOIST.1", "J_SENS.1", "J_DBG.1",
    ],
    # Ground (single logical net; KiCad symbol has several GND pads -> same net)
    "GND": [
        "J_PWR.2", "D1.A", "C_BULK1.-", "C_BULK2.2", "C_BULK3.2",
        "U1.GND", "C1.2", "C2.2", "C3.2", "C_EN.2",
        "SW1.2", "SW2.2",
        "U3.GND", "C_RTC.2", "BT1.-",
        "U4.GND", "C_INA.2", "U4.A0", "U4.A1",
        "U5.GND", "C_U5.2", "R_LK_RB.2", "C_LK.2", "U5.IN2+", "U5.IN2-",
        "C_MOIST.2",
        "U6.GND", "C_IN12.2", "C_OUT12.2", "R_FB12B.2", "D_CAT12.A",
        "U7.GND", "C_IN5.2", "C_OUT5.2", "R_FB5B.2", "D_CAT5.A",
        "U8.GND", "C_IN33.2", "C_OUT33.2",
        "Q1.S",
        "R1.2", "R_RP.2",
        "U9.V-", "C_DIMF.2",
        "J_LED.2", "J_FAN.1", "J_MOIST.2", "J_RES.2", "J_LEAK.2",
        "J_SENS.2", "J_STATUS.2", "J_DBG.4", "J_USB.GND", "J_USB.SHIELD",
    ],
    # I2C bus
    "SDA": ["U1.IO8", "R_SDA.2", "U3.SDA", "U4.SDA", "J_SENS.3"],
    "SCL": ["U1.IO9", "R_SCL.2", "U3.SCL", "U4.SCL", "J_SENS.4"],
    # RTC backup
    "VBAT": ["U3.VBAT", "BT1.+"],
    # MCU EN / boot
    "EN": ["U1.EN", "R_EN.2", "C_EN.1", "SW2.1"],
    "IO0_BOOT": ["U1.IO0", "SW1.1"],
    # Moisture ADC front end
    "MOIST_SIG": ["J_MOIST.3", "R_MOIST.1"],
    "MOIST_ADC": ["R_MOIST.2", "C_MOIST.1", "U1.IO4"],
    # Reservoir
    "RES_LOW_SW": ["U1.IO5", "J_RES.1"],
    "RES_LEVEL_ADC": ["U1.IO6", "J_RES.3"],
    # Leak comparator: trace -> +in (pull-up), divider -> -in, OC out -> IO7
    "LEAK_SENSE": ["J_LEAK.1", "R_LK_PU.2", "U5.IN1+", "C_LK.1"],
    "LEAK_REF": ["U5.IN1-", "R_LK_RA.2", "R_LK_RB.1"],
    "LEAK_DET": ["U5.OUT1", "R_LK_OUT.2", "U1.IO7"],
    # LED heatsink NTC (optional) divider to IO2 (R_NTC.1 -> +3V3 above)
    "LED_NTC": ["J_LED.4", "U1.IO2", "R_NTC.2"],
    # Pump drive
    "PUMP_PWM": ["U1.IO10", "R2.1"],
    # LED dim (PWM-direct populated; unity-buffer op-amp path is DNP, output ties to IN-)
    "LED_DIM": ["U1.IO14", "R_DIM.1"],
    "LED_DIM_OUT": ["R_DIM.2", "J_LED.3", "U9.OUT", "U9.IN-"],
    "DIM_FILT": ["R_DIMF.2", "C_DIMF.1", "U9.IN+"],
    "DIM_PWM_TAP": ["R_DIMF.1"],  # PWM tap if op-amp path fitted (DNP)
    "U9_VDD": ["U9.V+"],  # +5V if fitted (DNP)
    # Status LED data
    "STATUS_DATA": ["U1.IO21", "R_DATA.1"],
    "STATUS_DATA_OUT": ["R_DATA.2", "J_STATUS.3"],
    # USB / UART
    "USB_DM": ["U1.IO19", "J_USB.D-"],
    "USB_DP": ["U1.IO20", "J_USB.D+"],
    "VBUS": ["J_USB.VBUS"],
    "UART_TX": ["U1.IO43", "J_DBG.2"],
    "UART_RX": ["U1.IO44", "J_DBG.3"],
    # Fan drive (DNP, reserved) — 4-pin PWM fan: PWM out to fan, tach in (pull-up to 3V3)
    "FAN_PWM": ["U1.IO12", "R_FANG.1"],
    "FAN_PWM_OUT": ["R_FANG.2", "J_FAN.3"],
    "FAN_TACH": ["U1.IO13", "R_TACH.1", "J_FAN.4"],
    # Expansion (DNP headers)
    "EXP_HX711_DT": ["U1.IO15", "J_EXP.1"],
    "EXP_HX711_SCK": ["U1.IO16", "J_EXP.2"],
    "EXP_GP1": ["U1.IO17", "J_EXP.3"],
    "EXP_GP2": ["U1.IO18", "J_EXP.4"],
    "EXP_CAM1": ["U1.IO47", "J_CAM.1"],
    "EXP_CAM2": ["U1.IO48", "J_CAM.2"],

    # ---------- status LED board (PCB2) ----------
    "S_+5V": ["J_STA.1", "D_LVD.A", "C_LBULK.1"],
    "S_VLED": ["D_LVD.K", "LED1.VDD", "LED2.VDD", "LED3.VDD", "LED4.VDD", "LED5.VDD",
               "C_L1.1", "C_L2.1", "C_L3.1", "C_L4.1", "C_L5.1"],
    "S_GND": ["J_STA.2", "C_LBULK.2", "LED1.GND", "LED2.GND", "LED3.GND", "LED4.GND", "LED5.GND",
              "C_L1.2", "C_L2.2", "C_L3.2", "C_L4.2", "C_L5.2"],
    "S_DIN": ["J_STA.3", "LED1.DIN"],
    "S_D12": ["LED1.DOUT", "LED2.DIN"],
    "S_D23": ["LED2.DOUT", "LED3.DIN"],
    "S_D34": ["LED3.DOUT", "LED4.DIN"],
    "S_D45": ["LED4.DOUT", "LED5.DIN"],
    "S_D5OUT": ["LED5.DOUT"],  # chain end (no-connect)
}

# Nets that are *allowed* to have a single connected pin (reserved/no-connect/DNP-only), with reason.
SINGLE_PIN_OK = {
    "VBUS": "USB VBUS not used to power the board (bus-powered flashing only)",
    "S_D5OUT": "WS2812 chain end (DOUT of last LED is a no-connect)",
    "DIM_PWM_TAP": "0-10V op-amp dim path is DNP (PWM-direct dim populated)",
    "U9_VDD": "op-amp supply — DNP path",
}

# DNP-only/reserved nets excluded from the >=2-active-pin rule (their parts are DNP).
RESERVED_NETS = {
    "PH12", "+12V", "FB12", "BOOT12",            # 12V buck DNP
    "DIM_FILT", "U9_VDD", "DIM_PWM_TAP",         # op-amp dim DNP
    "FAN_PWM", "FAN_PWM_OUT", "FAN_TACH",        # fan DNP (4-pin PWM provision)
    "EXP_HX711_DT", "EXP_HX711_SCK", "EXP_GP1", "EXP_GP2", "EXP_CAM1", "EXP_CAM2",  # expansion DNP
    "LED_NTC",                                   # optional NTC
}


def _pin_ref(pin: str) -> str:
    return pin.split(".", 1)[0]


def _norm_pins() -> dict[str, list[str]]:
    """Drop the '.../x' duplicate-pad disambiguators used so one physical pad can sit on two
    logical lines in this functional model (e.g. a connector GND pad). Returns net->pins."""
    out = {}
    for net, pins in NETS.items():
        cleaned = []
        for p in pins:
            ref, _, pinname = p.partition(".")
            pinname = pinname.rstrip("x")  # 'J_PUMP.1x' -> connector GND pad alias
            cleaned.append(f"{ref}.{pinname}")
        out[net] = cleaned
    return out


# ----------------------------------------------------------------------------- emit
def emit_csv() -> str:
    rows = ["net,ref,pin,populated,part"]
    for net, pins in NETS.items():
        for p in pins:
            ref, _, pin = p.partition(".")
            c = COMPONENTS.get(ref)
            pop = "Y" if (c and c.populated) else ("DNP" if c else "?")
            part = c.part if c else "?"
            rows.append(f"{net},{ref},{pin},{pop},{part}")
    return "\n".join(rows) + "\n"


def emit_kicad() -> str:
    """A minimal KiCad-style flat netlist (importable to seed PCB layout)."""
    out = ["(export (version D)", "  (components"]
    for ref, c in COMPONENTS.items():
        dnp = " (property (name \"dnp\") (value \"1\"))" if not c.populated else ""
        out.append(f"    (comp (ref \"{ref}\") (value \"{c.value}\") "
                   f"(footprint \"{c.footprint}\") (datasheet \"{c.part}\"){dnp})")
    out.append("  )")
    out.append("  (nets")
    for i, (net, pins) in enumerate(_norm_pins().items(), start=1):
        out.append(f"    (net (code \"{i}\") (name \"{net}\")")
        for p in pins:
            ref, _, pin = p.partition(".")
            out.append(f"      (node (ref \"{ref}\") (pin \"{pin}\"))")
        out.append("    )")
    out.append("  )")
    out.append(")")
    return "\n".join(out) + "\n"


# ----------------------------------------------------------------------------- ERC check
def _read_pinmap_nets() -> dict[str, str]:
    """net-name -> esp32 gpio, from pin-map.csv (the firmware pin contract)."""
    m = {}
    if not PIN_MAP.exists():
        return m
    with PIN_MAP.open() as f:
        for row in csv.DictReader(f):
            m[row["net"].strip()] = row["esp32s3_gpio"].strip()
    return m


def _read_bom_refs() -> set[str]:
    """All designators in the BOM. A BOM row's `ref` cell may list several space-separated
    designators (grouped passives), so split it."""
    refs = set()
    if not BOM.exists():
        return refs
    with BOM.open() as f:
        for row in csv.DictReader(f):
            for d in row["ref"].split():
                refs.add(d.strip())
    return refs


# pin-map net -> (this netlist's net name, expected MCU pin)  [firmware contract cross-check]
PINMAP_TO_NET = {
    "I2C_SDA": ("SDA", "IO8"), "I2C_SCL": ("SCL", "IO9"),
    "MOISTURE_ADC": ("MOIST_ADC", "IO4"),
    "RES_LOW_SW": ("RES_LOW_SW", "IO5"), "RES_LEVEL_ADC": ("RES_LEVEL_ADC", "IO6"),
    "LEAK_DET": ("LEAK_DET", "IO7"), "LED_HS_NTC": ("LED_NTC", "IO2"),
    "PUMP_PWM": ("PUMP_PWM", "IO10"),
    "FAN_PWM": ("FAN_PWM", "IO12"), "FAN_TACH": ("FAN_TACH", "IO13"),
    "LED_DIM_PWM": ("LED_DIM", "IO14"), "STATUS_LED_DATA": ("STATUS_DATA", "IO21"),
    "UART0_TX": ("UART_TX", "IO43"), "UART0_RX": ("UART_RX", "IO44"),
    "USB_DM": ("USB_DM", "IO19"), "USB_DP": ("USB_DP", "IO20"),
    "EXP_HX711_DT": ("EXP_HX711_DT", "IO15"), "EXP_HX711_SCK": ("EXP_HX711_SCK", "IO16"),
    "EXP_GP1": ("EXP_GP1", "IO17"), "EXP_GP2": ("EXP_GP2", "IO18"),
    "EXP_CAM1": ("EXP_CAM1", "IO47"), "EXP_CAM2": ("EXP_CAM2", "IO48"),
}
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

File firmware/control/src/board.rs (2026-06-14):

//! On-target frame-assembly helpers (host-tested). Turns raw board readings into a [`SensorFrame`],
//! applying the documented GPIO polarity. This logic used to live inline in the esp-hal binding
//! (`controller/hw.rs`), where cargo could never test it; pulling it here closes a real blind spot
//! — a swapped field or wrong pin polarity is silent and would only surface on hardware.
//!
//! The two boolean pin states are wrapped in newtypes so they **cannot be swapped** at the call
//! site (a compile error), and the polarity is documented + asserted once, here.

use crate::app_state::SensorFrame;
use crate::hal::{SensorError, TempRh, WallTime};

/// Raw state of the reservoir float-switch pin. Pin map `RES_LOW_SW`: internal pull-up, the switch
/// closes (pin LOW) when the reservoir is LOW. `true` = pin reads low.
///
/// ASSUMPTION to confirm at WI-EE-08 bring-up: the float's NO/NC orientation matches "closed = low
/// water". A host test cannot verify the physical wiring — only that the firmware applies *this*
/// documented convention.
#[derive(Debug, Clone, Copy, PartialEq, Eq)]
pub struct ReservoirFloatLow(pub bool);

/// Raw state of the leak-detect pin. Pin map: comparator output, **active-HIGH = leak**.
/// `true` = pin reads high.
#[derive(Debug, Clone, Copy, PartialEq, Eq)]
pub struct LeakPinHigh(pub bool);

/// Assemble a [`SensorFrame`] from raw board readings, applying GPIO polarity. The newtype
/// parameters make the reservoir/leak booleans impossible to transpose.
#[allow(clippy::too_many_arguments)]
pub fn build_sensor_frame(
    now_ms: u64,
    rtc: WallTime,
    temp_rh: Result<TempRh, SensorError>,
    moisture_raw: Result<u16, SensorError>,
    reservoir: ReservoirFloatLow,
    leak: LeakPinHigh,
    led_heat_c: Option<f32>,
) -> SensorFrame {
    SensorFrame {
        now_ms,
        rtc,
        temp_rh,
        moisture_raw,
        reservoir_low: reservoir.0, // RES_LOW_SW closed (LOW) == reservoir low
        leak: leak.0,               // active-HIGH == leak
        led_heat_c,
    }
}

#[cfg(test)]
mod tests {
    use super::*;

    #[test]
    fn maps_fields_and_polarity() {
        let f = build_sensor_frame(
            123,
            WallTime {
                valid: true,
                unix_s: 42,
            },
            Ok(TempRh {
                temp_c: 24.0,
                rh_pct: 60.0,
            }),
            Ok(2000),
            ReservoirFloatLow(true), // pin low => reservoir LOW
            LeakPinHigh(false),      // pin low => no leak
            Some(55.0),
        );
        assert_eq!(f.now_ms, 123);
        assert_eq!(f.rtc.unix_s, 42);
        assert_eq!(f.moisture_raw, Ok(2000));
        assert!(f.reservoir_low, "float pin low must map to reservoir_low");
        assert!(!f.leak, "leak pin low must map to no leak");
        assert_eq!(f.led_heat_c, Some(55.0));
    }

    #[test]
    fn leak_high_maps_to_leak_reservoir_high_maps_to_not_low() {
        let f = build_sensor_frame(
            0,
            WallTime::INVALID,
            Err(SensorError::Bus),
            Err(SensorError::NotPresent),
            ReservoirFloatLow(false), // pin high => reservoir NOT low
            LeakPinHigh(true),        // pin high => leak
            None,
        );
        assert!(f.leak);
        assert!(!f.reservoir_low);
        assert!(f.temp_rh.is_err());
        assert!(f.moisture_raw.is_err());
    }

    // End-to-end: a leak pin high, assembled into the frame and run through the App, must drive the
    // LEAK_DETECTED warning state — proving the whole controller-side path (board reading -> frame
    // -> control) on the host, not just the App in isolation. (V1 is passive: leak is a warning, not
    // a pump lockout — there is no pump.)
    #[test]
    fn assembled_leak_frame_drives_leak_state() {
        use crate::app_state::{App, AppConfig};
        use crate::calibration::Calibration;
        use crate::led_status::LedColor;
        use crate::safety_controller::SystemState;
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

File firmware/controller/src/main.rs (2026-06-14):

//! OpenCanopy ESP32-S3 firmware binary. Boots and runs the deterministic control loop (§9.2)
//! against the real esp-hal peripheral drivers in [`hw`], wired to the committed pin map.
//!
//! All control policy lives in the platform-agnostic `control` crate (host-tested, §10.2); this
//! binary is the hardware binding. Build with `--features emulator` to run the loop with fast
//! simulated timing + serial telemetry for the Wokwi smoke test (`controller/wokwi/`); the default
//! build runs the production 5-minute cadence.
//!
//! STATUS: the esp-hal driver code is verified by cross-compilation and the Wokwi run (with mock
//! I2C chips); calibration values and the WS2812 status-LED RMT driver are completed/validated at
//! WI-EE-08 bring-up against real hardware and the finalized pin map.

#![no_std]
#![no_main]

mod hw;

use control::app_state::FIRMWARE_VERSION;
use esp_backtrace as _;
use esp_println::println;

#[esp_hal::main]
fn main() -> ! {
    // Default clock config (forcing CpuClock::max reconfigures the PLL, which the Wokwi emulator
    // doesn't fully model and can hang boot; the default is fine for this controller).
    let peripherals = esp_hal::init(esp_hal::Config::default());
    println!("=== OpenCanopy firmware v{FIRMWARE_VERSION} (ESP32-S3) ===");
    hw::run(peripherals)
}

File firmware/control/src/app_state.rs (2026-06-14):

//! Top-level orchestrator: wires the plant profile, light/moisture/climate monitors, safety state
//! machine, LED panel, calibration and logging into one deterministic per-tick `step`.
//!
//! This is the integration seam the simulator (`sim/`) and the on-target `controller/` both drive:
//! they supply a [`SensorFrame`] from real or simulated peripherals, and apply the returned
//! [`Commands`] back to the actuator. **V1 is passive (no pump) and fan-less (ECO-003/ECO-001): the
//! grow LED is the only actuator.** Watering is monitored and warned, never actuated. All policy
//! lives in the individual modules; this sequences them and enforces the LED gate on top.

use crate::calibration::{self, LoadedCalibration};
use crate::climate_controller::{self, ClimateInputs};
use crate::hal::{SensorError, TempRh, WallTime};
use crate::led_status::{self, LightHealth, MoistureHealth, Panel, PanelInputs, WaterLevel};
use crate::light_controller::{self, LightInputs};
use crate::logging::{LogEntry, LogKind, OnboardLog};
use crate::moisture_monitor::{self, MoistureStatus, MoistureValidator};
use crate::plant_profile::{self, Setpoints, Stage};
use crate::safety_controller::{BootReport, Gates, SafetyController, SafetyInputs, SystemState};

const DAY_MS: u64 = 86_400_000;
/// Firmware version stamped into logs (§9.10).
pub const FIRMWARE_VERSION: u16 = 1;
/// Log a periodic sensor snapshot at most this often (§9.10: every 5–15 min). 10 min here.
const SENSOR_LOG_INTERVAL_MS: u64 = 10 * 60_000;
/// Critical over-temp air threshold (§9.5): above this the LED is cut.
const OVER_TEMP_C: f32 = 35.0;

/// One frame of sensor data + environment for a control tick.
#[derive(Debug, Clone, Copy)]
pub struct SensorFrame {
    pub now_ms: u64,
    pub rtc: WallTime,
    pub temp_rh: Result<TempRh, SensorError>,
    pub moisture_raw: Result<u16, SensorError>,
    /// Reservoir at/below the low-level mark — refill prompt (V1 passive, ECO-003).
    pub reservoir_low: bool,
    /// Catch-tray wet — flood/overflow warning.
    pub leak: bool,
    pub led_heat_c: Option<f32>,
}

/// Commanded actuator output + observability for one tick. The LED is the only actuator.
#[derive(Debug, Clone, Copy, PartialEq)]
pub struct Commands {
    pub led_pct: u8,
    pub state: SystemState,
    pub panel: Panel,
    pub stage: Stage,
    pub light_on: bool,
    pub vpd_kpa: f32,
    /// `None` when the moisture sensor is invalid/untrusted (§7.6).
    pub moisture_pct: Option<f32>,
    /// Observability: moisture warning classification this tick (passive monitor, ECO-003).
    pub moisture_status: MoistureStatus,
    /// Observability: LED power was reduced by thermal/heat-sink derating this tick (§9.5).
    pub led_derated: bool,
    /// Observability: climate (temp/RH/VPD) outside the preferred band — folds into the System LED.
    pub climate_warn: bool,
    /// Observability: running the RTC-invalid safe-schedule fallback (§9.4).
    pub rtc_fallback: bool,
}

/// Configuration fixed at construction.
#[derive(Debug, Clone, Copy, Default)]
pub struct AppConfig {
    /// Fixed UTC offset in seconds for local time-of-day (V1 has no DST). Default 0 = UTC.
    pub utc_offset_s: i32,
}

/// The whole controller. Owns all persistent sub-controller state.
pub struct App {
    cfg: AppConfig,
    cal: LoadedCalibration,
    safety: SafetyController,
    moisture: MoistureValidator,
    log: OnboardLog,
    boot_ms: u64,
    age_days_base: u32,
    maintenance: bool,
    last_sensor_log_ms: Option<u64>,
    last_logged_state: Option<SystemState>,
    last_reservoir_low: bool,
}

impl App {
    /// Construct and run the §9.4 boot sequence. `stored_cal` is the raw calibration record from
    /// flash (`None` = none present). `restored_age_days` comes from NVS/RTC (§9.4 step 5).
    pub fn boot(
        cfg: AppConfig,
        stored_cal: Option<&[u8]>,
        restored_age_days: u32,
        boot_ms: u64,
        rtc: WallTime,
        self_test_passed: bool,
    ) -> App {
        let cal = calibration::load(stored_cal);
        let mut safety = SafetyController::new();
        safety.boot(BootReport {
            self_test_passed,
            calibration_valid: cal.source == calibration::CalSource::Valid,
            sensors_in_range: true,
            restored_age_days,
            rtc_valid: rtc.valid,
            // §9.4 step 7: the LED (only actuator) is forced off before anything else.
            led_forced_off: true,
        });
        let mut app = App {
            cfg,
            cal,
            safety,
            moisture: MoistureValidator::default(),
            log: OnboardLog::new(),
            boot_ms,
            age_days_base: restored_age_days,
            maintenance: false,
            last_sensor_log_ms: None,
            last_logged_state: None,
            last_reservoir_low: false,
        };
        // Stamp versions at boot (§9.10).
        app.log.push(LogEntry {
            ts_unix_s: rtc.unix_s,
            ts_valid: rtc.valid,
            kind: LogKind::Versions {
                firmware: FIRMWARE_VERSION,
                calibration: app.cal.cal.version,
            },
        });
        app
    }

    pub fn state(&self) -> SystemState {
        self.safety.state()
    }
    pub fn log(&self) -> &OnboardLog {
        &self.log
    }
    pub fn calibration(&self) -> &LoadedCalibration {
        &self.cal
    }
    pub fn set_maintenance(&mut self, on: bool) {
        self.maintenance = on;
    }
    /// Service action: clear a latched leak (§11.4).
    pub fn clear_leak(&mut self) {
        self.safety.clear_leak();
    }
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

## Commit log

2026-06-13 Build 00-project-setup track: repo skeleton, licenses, templates, scope lock, risk register, CI
    Implements the full Project & Repo track (WI-PS-01..06):
    - WI-PS-01: directory tree per spec §14.1, subtree READMEs, tuned .gitignore.
    - WI-PS-02: per-asset licenses (Apache-2.0 firmware, CERN-OHL-S v2 hardware/mech,
    CC BY 4.0 docs) + REUSE-style mapping with photos/logs PII condition.
    - WI-PS-03: five GitHub issue forms, PR template (work-item-ID gated), CONTRIBUTING.
    - WI-PS-04: docs/product-requirements.md (locked envelope) + docs/scope.md (non-goals).
    - WI-PS-05: docs/risk-register.md (§22 engineering + §17 safety risks, owners, links).
    - WI-PS-06: ci.yml (markdown+link, Rust fmt/clippy/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
2026-06-13 README: reflect built/published state (Rust firmware, docs site, in-repo resources)
    - Note firmware is Rust (no_std + esp-hal) on ESP32-S3.
    - Add docs-site link, CONTRIBUTING/templates, and in-repo LICENSES pointers.
    - Replace "created as the build progresses" with the now-in-place subtree layout
    and a project-status section; note the §23 design-review additions and n=2 trial.
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2026-06-13 electronics: build EE track — PoC, power, schematic, PCB, harness, reports, fab, bring-up/HIL
    Work the Electronics track (WI-EE-01..10) in dependency order, grounded in the
    locked V1 spec. Each work item gets its engineering design artifact; physical
    bench/fab/firmware-gated steps are flagged rather than overclaimed.
    - EE-10 thermal budget (DR-01 thermal half): thermal_budget_model.py + report.
    50/80 W GO, 100 W marginal (Tj 86 C) GO-with-mitigation.
    - EE-02 power budget: power-budget.csv + report; 120/150 W PSU, rails >=20%.
    - EE-01 component PoC: selection + BOM entries + bench protocol + log template.
    - EE-03 schematic: 5-sheet capture, pin-map.csv, protection chain, fail-OFF pump.
    -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
    [alternates.csv, bom.csv, harness-table.csv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]
2026-06-13 electronics: reconcile DR-01 gate after WI-PL-06 landed (photometric PASS)
    The rebase brought in the plant-science track, including WI-PL-06 (photometric
    model) — now Done/PASS. Update the electronics DR-01 references accordingly:
    - Both halves of DR-01 now pass (EE-10 thermal + PL-06 photometric); the
    light-purchase / CAD-freeze gate is clear.
    - Fold in PL-06's form-factor result: a PANEL meets >=0.6 uniformity at the
    150 mm clearance target; a single BAR only reaches it at >=200-225 mm.
    Compact frame is height-constrained (DR-07) -> panel preferred.
    - bom.csv: grow-light candidate -> panel form, status CANDIDATE-DR01-PASS,
    PPFD ref points at the real PL-06 maps; still passes bom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
    [alternates.csv, bom.csv]
2026-06-13 risk-register: record R8 — EE-08 bring-up/HIL blocked on WI-FW-07
    Add engineering risk R8: in-hardware safety verification (pump fail-off S6,
    leak lockout S5) via EE-08 bring-up + HIL is gated on the firmware safety
    state machine WI-FW-07 (Not started). Mitigation: sequence FW-07 ahead of
    board fab; dry-validate the HIL fixture against the sim/HAL mocks meanwhile.
    The pump-fail-off hardware guarantee (gate pull-down) is firmware-independent.
    Logged in the change log per the register's change-control rule.
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2026-06-13 firmware: ESP32-S3 emulator smoke test (Wokwi) for the controller binary
    Adds a CI-level smoke test that runs the REAL firmware binary on emulated
    silicon — the integration layer the host unit tests and sim/ can't reach
    (esp-hal init, boot, control loop, serial). Complements, does not replace, HIL.
    - controller `emulator` Cargo feature + src/emulator.rs: boots the genuine
    control::App with valid calibration and runs ~1 simulated day of the 5-min
    control loop on emulated hardware, driven by synthesized sensors (dries out →
    waters → recovers), emitting UART telemetry. Effectively sim/ on-silicon.
    - main.rs: serial boot banner + dispatch to the emulator path under the feature;
    re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
    [main.rs]
2026-06-13 mechanical: worst-case interference simulation (FCL) + fixes
    Validate fit/clearance by simulation instead of trial prints. Adds
    collision_check.py: runs the actual placed models through FCL
    (python-fcl) with a configurable manufacturing error margin and proves
    every clearance fit survives the worst case.
    - Found and fixed 8 real interferences the nominal model had missed
    (reservoir-in-rails, lid rim, channel-through-tray, bay-through-rail,
    drawer-blocked-by-front-rail, light-carrier-into-bay, fan unattached
    then clipping the pot).
    - Opened the frame front (drawer + pot access), added a rear cross-rail
    for the fan, corrected BAY_BACK_Y, anchored the light carrier, lid
    rebate. Reduc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
    [cable-channel.step, cable-channel.stl, coupon-snap-fit.step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]
2026-06-13 mechanical+docs: full-assembly sketch renders on the Pages site
    Add multi-angle renders of the complete assembly so reviewers can
    inspect/comment on the whole build, and publish them on GitHub Pages.
    - build.py now also exports placed assembly meshes (every part in its
    assembly position) to mechanical/stl/assembly/ — the CI-light input
    for rendering/collision, needing no OpenCascade kernel.
    - render.py: numpy+matplotlib+trimesh (headless) sketch renders, one
    per camera angle (front/right/back/top + 2 isometrics), each part a
    distinct colour with a legend. ~15 s, reads the committed meshes.
    - docs/mechanical-build.md embeds the 6 views; docs.yml (Pages CI) gains
    a render step tha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
    [cable-channel.stl, electronics-dry-bay-lid.stl, electronics-dry-bay.stl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]
2026-06-13 firmware/controller: make the ESP32-S3 cross-compile actually link
    Verified the controller binary cross-compiles for xtensa-esp32s3-none-elf with
    the Espressif Rust channel (espressif/idf-rust container) — default, emulator,
    and telemetry feature builds all link into a ~125 KB ELF. control/ itself
    compiles for the bare-metal target, confirming the no_std / no-esp-hal boundary.
    Fixes found by actually building it:
    - esp-println: default-features=false + single output feature `uart` (the
    jtag-serial|uart|auto group requires exactly one).
    - esp-hal: add `unstable` feature (gates the entry macro, time, Delay in 0.23).
    - add heapless dep (used by the calibration-store binding).
    - .cargo/conf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
    [main.rs]
2026-06-13 ci: use official wokwi/wokwi-ci-action for the ESP32-S3 emulator smoke test
    Replaces the fragile manual `curl | sh` install of wokwi-cli with the supported
    GitHub Action (robust install + invocation). Gates the job on WOKWI_CLI_TOKEN
    being present (skips cleanly on forks). Builds the emulator ELF then runs the
    Wokwi scenario, asserting the completion sentinel and failing on "panicked".
2026-06-13 mechanical/render: switch to VTK (z-buffered) — fix clipping & shading
    The matplotlib mplot3d renders showed painter's-algorithm artifacts:
    faces clipped through each other (no z-buffer) and flat surfaces looked
    patchy with visible triangulation diagonals. Re-do render.py with VTK,
    a real z-buffered renderer:
    - correct occlusion (no clipping), uniform flat/Gouraud face colour;
    - vtkFeatureEdges draws only real edges/silhouettes (42 deg crease), not
    triangulation seams; normals smoothing rounds the pot;
    - legend moved to its own side viewport (no overlap); parallel projection
    for a clean technical look; ~1.5 s for all 6 views (was ~13 s).
    - docs.yml render step now installs trimesh + v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
2026-06-13 firmware/controller: fix emulator serial route for Wokwi (UART0 -> USB-Serial-JTAG)
    The Wokwi smoke test failed: I'd built esp-println with the `uart` feature
    (UART0), but Wokwi's ESP32-S3 board monitors the USB-Serial-JTAG console, so the
    firmware's serial output never reached Wokwi and the scenario timed out.
    Fix: use esp-println's default `auto` console (selects USB-Serial-JTAG on the
    S3 — what real esp-rs Wokwi examples rely on) and drop the now-irrelevant UART
    serial wiring from diagram.json. Emulator build re-verified for xtensa in the
    espressif/idf-rust container.
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2026-06-13 firmware/controller: fix Wokwi boot — default clock + auto (JTAG) console
    Serial was empty for BOTH uart and auto consoles → the firmware wasn't booting,
    not a console-routing issue. Root cause: esp_hal::init() forced CpuClock::max(),
    whose PLL reconfiguration the Wokwi emulator doesn't fully model and which hangs
    boot before the first print. Use the default clock config, and put esp-println
    back to its default `auto` console (USB-Serial-JTAG on the S3 — what the official
    esp-hal Wokwi examples use and what Wokwi reports).
    [main.rs]
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2026-06-13 mechanical: v0 OpenSCAD block model — electronics in base, beside reservoir, walled
    Clean v0 parametric block model per docs/cad_brief_for_claude.md, with the
    current architecture decision: ELECTRONICS LIVE IN THE BASE, BESIDE the water
    reservoir, isolated by an additional vertical wall (side-by-side wet | wall | dry).
    - mechanical/cad/opencanopy_tabletop_pepper_v1_block_model.scad — 10 modules,
    simple solids only; compiles clean in OpenSCAD, watertight, envelope 480x320x680.
    - Open-frame cage (corner posts + top ring), open front and sides; fixed LED bar
    under the hood; status-LED strip on the front; no screen/controls.
    - Screenshots (incl. a base-internals view showing wet | isola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
    [opencanopy_tabletop_pepper_v1_block_model.scad, opencanopy_v0.stl]
2026-06-13 control: host-tested I2C device protocol logic (SHT40, DS3231, INA219)
    Puts the error-prone part of the I2C drivers — register maps, command bytes,
    SHT4x CRC-8, DS3231 BCD/OSF decoding, INA219 raw->mA / calibration math — as
    pure, host-testable functions in the control crate (11 new tests, incl. the
    SHT4x CRC datasheet vector). The on-target esp-hal binding (next) just does the
    bus transaction and calls these; the same code backs the Wokwi mock chips.
    This catches I2C driving-logic bugs off-hardware, before any board is ordered.
    [i2c_devices.rs, lib.rs]
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2026-06-13 firmware/controller: implement real esp-hal drivers (I2C/ADC/GPIO/LEDC)
    Replaces the unimplemented!() peripheral stubs with a real hw.rs binding wired to
    the committed pin map: I2C0 reads SHT40/DS3231/INA219 via the host-tested
    control::i2c_devices parsers, ADC1 reads the capacitive moisture probe, GPIO
    reads leak + reservoir-float, and LEDC drives pump/fan/grow-LED PWM. The control
    loop now runs against these real drivers (default = 5-min cadence; `emulator`
    feature = fast timing + telemetry for Wokwi). Cross-compiles clean for
    xtensa-esp32s3 (default + emulator).
    This also removes the earlier "panics at Platform::new on real hardware" gap.
    Deferred to bring-up: WS2812 status LEDs (no esp-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
    [hw.rs, main.rs]
2026-06-13 mechanical/v0: fix the block model + render it properly (VTK) + collision sim
    Address the render-quality problems in the v0 OpenSCAD model:
    - pot is now HOLLOW (open top, walls, central drain hole) — not a solid blob;
    - frame OPEN at the back (rear support panel removed) — open front/sides/back;
    - base split: wet reservoir | additional isolating wall | dry electronics, with
    the electronics well clear of the cabinet walls;
    - $fn=120; coincident faces inset to stop z-fighting.
    render_block.py: exports each part (OpenSCAD CGAL), renders 8 angles with VTK
    (real z-buffer: smooth, correct occlusion, clean feature edges) + a labelled
    colour legend, and runs an FCL part-vs-part COLLISION CHEC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
    [opencanopy_tabletop_pepper_v1_block_model.scad, opencanopy_v0.stl]
2026-06-13 firmware: host-test the full I2C driver stack with mocks (no Wokwi needed)
    Moves the I2C *transaction* logic (write command, read registers, parse, handle
    NAK) out of controller/hw.rs into control::i2c_devices, generic over a minimal
    I2cBus/DelayMs trait so it's host-testable. Adds a mock I2C bus simulating
    SHT40/DS3231/INA219 and 8 integration tests covering: measure-command issuance,
    register reads, CRC/Protocol vs Bus errors, device-absent NAK, OSF→invalid,
    and the INA219 calibration write. controller/hw.rs is now a thin esp-hal adapter
    (newtype impls of the traits) — cross-compiles clean for xtensa.
    This validates "missing I2C support / I2C driving logic" cheaply in `cargo test`
    ins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
    [hw.rs, i2c_devices.rs, lib.rs]
2026-06-13 mechanical/v0: remove the fan entirely
    Drop the fan from the block model, renders and collision set (conflicting
    instruction resolved — no fan in V1). Modules, dispatch, legend and the
    FCL collision pairs updated; renders regenerated (collision check still PASS).
    [opencanopy_tabletop_pepper_v1_block_model.scad, opencanopy_v0.stl]
2026-06-13 firmware/wokwi: validate real I2C driver on emulated silicon (native DS1307)
    Wokwi smoke test now wires a native DS1307 RTC (same 0x68 + BCD layout as the
    DS3231) + 4.7k I2C pull-ups + a moisture divider to the real firmware. Result on
    emulated ESP32-S3: `rtc_valid=true` — the real esp-hal I2C bus + read_ds3231
    driver (addressing, write_read register reads, BCD decode) work end-to-end; the
    light schedule runs off the valid RTC; and the firmware correctly fail-safes to
    SENSOR_FAULT for the absent SHT40/INA219/moisture (§7.6). Reaches the completion
    sentinel (CI-usable).
    Cut the emulator run to 8 ticks (absent-device I2C NAKs are slow under emulation;
    288 ticks won't finish in the CI timeo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
    [hw.rs]
2026-06-13 control: host-test SensorFrame assembly + GPIO polarity (close hw.rs blind spot)
    The frame assembly (which reading -> which field) and the reservoir/leak GPIO
    polarity used to live inline in the esp-hal-only controller/hw.rs, where cargo
    could never test it — a swapped field or wrong polarity would be silent until
    hardware. Moved it into control::board::build_sensor_frame (host-tested, 3 tests
    incl. an end-to-end leak->LEAK_DETECTED path) with ReservoirFloatLow/LeakPinHigh
    newtypes so the two pin booleans can't be transposed at the call site. hw.rs now
    calls it; cross-compiles clean.
    [board.rs, hw.rs, lib.rs]
2026-06-13 mechanical/v0: rounded furniture frame, feet, hollow-post cabling, fastening
    Review fixes to the v0 block model:
    - rounded edges on base, posts, hood and feet (furniture look from the reference);
    - 4 feet so the unit stands off the countertop;
    - cables route through HOLLOW posts — dedicated cable channel removed;
    - fastening scheme added: M3 heat-set inserts + socket screws at the post joints
    (modelled as the `screws` part), dowel pins for alignment, print-in-panels
    rationale (480 mm > consumer beds) — documented in docs/fastening.md.
    Renders regenerated (VTK, labelled, 8 angles incl. base cutaway); FCL collision
    check PASS (electronics clear the walls). docs/mechanical-build.md upd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
    [opencanopy_tabletop_pepper_v1_block_model.scad]
2026-06-14 control: fix clippy manual_checked_ops in ina219_calibration (CI on rust 1.96)
    CI's stable clippy (1.96) added the manual_checked_ops lint, which -D warnings
    turns into an error; my older local clippy (1.93) never saw it. Use checked_div
    (→ 0 on a zero denominator) instead of the manual `if denom == 0` guard. Same
    behavior; verified with `cargo +stable clippy` on 1.96.
    [i2c_devices.rs]
2026-06-14 mechanical: v1 aesthetic product model (Scandinavian appliance)
    Redesign the form (same functional architecture: electronics + reservoir in the
    base, side by side, separated by a sealed wall; open-frame; no screen; 4 status LEDs):
    - two continuous ROUNDED SIDE-FRAME ARCHES replace the four posts;
    - slim TOP LIGHT BRIDGE instead of a top cage (LED grow bar under it);
    - slimmer FOOTED base, rounded corners, recessed rear service bay;
    - raised WOOD SHELF with a recessed circular POT WELL (integrated pot);
    - small PILL status diffuser (4 LED dots) replaces the front panel;
    - material grouping: white shell / wood / dark recessed service / reservoir.
    Dims: 480x320x680, base 120, bridge 52, side-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
    [opencanopy_tabletop_pepper_v1_block_model.scad]
2026-06-14 docs: publish firmware Rust API docs (cargo doc) to GitHub Pages
    The docs workflow now builds `cargo doc` for the host crates (control + sim) and
    stages it under /api on the Pages site, with a landing redirect and a new
    docs/firmware-api.md page linking to it. Rebuilds when firmware/control or
    firmware/sim change. rustdoc emits relative links, so it works served under /api/.
    Also fixed 7 rustdoc warnings (markdown ranges like [0,100] misread as doc-links;
    a public->private link; a StatusLeds path) so the generated docs are warning-clean.
    [calibration.rs, led_status.rs]
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2026-06-14 mechanical/v1: LED no longer floating — recessed into the bridge + mount screws
    The LED bar abutted the bridge with no visible attachment (read as floating). Now:
    - the bridge underside has a LED recess; the LED bar nests 8 mm up into it (emitter
    ~10 mm proud) — captured laterally + from above, like an integrated downlight;
    - 2 visible M3/M4 LED-mount screws up into the bridge.
    Collision PASS (LED↔bridge / LED↔screws whitelisted as intended fastening); LED + pot
    centroids still X=240.0 Y=160.0; free-standing physics sim still PASS.
    [opencanopy_tabletop_pepper_v1_block_model.scad, opencanopy_v0.stl]
2026-06-14 electronics: complete the electrical design — controller netlist, full BOM, connector + layout specs
    Completes the electronics design to the limit of what's deliverable without a
    KiCad GUI or a fabricated board, and makes the residual explicit.
    Schematic as data (WI-EE-03). electronics/pcb/netlist/controller_netlist.py is
    the single source of truth: 90 components (73 populated, 17 DNP) and 61
    pin-level nets — full power chain (fuse, reverse-pol P-FET + Zener clamp, TVS,
    bulk, two TPS5430 bucks + AP2112K LDO with their inductors/catch-diodes/
    feedback), MCU + EN/boot, I2C bus + pull-ups, INA219 + shunt, LM393 leak
    comparator, fail-OFF pump drive, PWM-direct LED dim, and the 5x WS2812 sta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
    [bom.csv, controller-netlist.csv]
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2026-06-14 mechanical: make v1 model interference- and float-clean; honest no-whitelist audit
    The renders showed parts visibly colliding and floating. Replace the
    whitelisted FCL collision check (which masked real overlaps by listing them
    as "expected contact") with audit.py: an honest geometry audit that measures
    the true boolean OVERLAP VOLUME of every part pair (so abutting faces aren't
    mistaken for interpenetration) and each part's nearest-neighbour gap (so an
    unsupported/floating part is caught). No whitelist.
    Fix the real geometry the audit exposed:
    - bridge now abuts the arch tops (X = side_t .. env_w-side_t) instead of being
    buried ~27 mm inside them
    - arch foot tenons / base sockets Z-align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
    [opencanopy_tabletop_pepper_v1_block_model.scad]
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2026-06-14 electronics+docs: rendered electronics-design doc; retire KiCad (tscircuit is the PCB tool)
    Adds a published, render-rich electronics design doc and makes the PCB toolchain
    coherent by retiring the unused KiCad path.
    docs/electronics-design.md (new): an extensive, reviewable walkthrough of the
    controller board — a per-subsystem tour (power input/protection, DC-DC rails,
    MCU+USB/UART, I2C+RTC+current monitor, moisture/reservoir, leak detect, the
    fail-OFF pump drive, LED dim+status), the safety design, the connector handoff,
    the BOM, and the headless netlist->Gerbers flow. 10 renders in
    docs/assets/renders/ (e-*.png), generated from the netlist:
    * 8 per-subsystem schematics (clean, labell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
    [bom.csv, controller.kicad_pcb]
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2026-06-14 mechanical: major redesign — two-pillar product (electronics at top, passive watering)
    Replace the arched-frame model with the new architecture (audit-clean):
    - low integrated BASE = a single wet zone: 6.6 L passive reservoir + grow well,
    NO electronics bay in the base
    - TWO wooden pillars (Ø28) rising from dry structural bosses
    - one slim top LED BLOCK spanning the pillars; the LED is centred over the grow
    module (offset 0.0/0.0 mm, <=5) and the small controller+driver board + USB-C
    live in the top block, under the bar, wrapped around the right pillar foot
    - a removable RAISED grow insert (slotted/perforated, semi-hydro), 0.5 mm wick gap
    - passive self-watering; no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
    [opencanopy_tabletop_pepper_v1_block_model.scad]
2026-06-14 electronics: check in WS2812B-2020 status-LED 3D model (STEP + WRL)
    Downloads the real 3D model for the status LEDs (LCSC C965555 / EasyEDA, via
    easyeda2kicad) and checks it into electronics/pcb/3d-models/ so mechanical can
    drop real geometry into the enclosure CAD: a BREP solid STEP (2.0x2.0x0.8 mm,
    matches the datasheet) + a WRL render mesh. README documents provenance,
    licensing (vendor/EasyEDA model — reference/visualisation), and how to
    regenerate. Sourcing doc + electronics README now point at the committed model.
    The KiCad library has no 2020 variant (its footprint references a model that
    404s) and SnapEDA/UltraLibrarian are auth-walled, so easyeda2kicad (no auth, by
    LCSC part numb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
    [WS2812B-2020_C965555.step]
2026-06-14 mechanical: centre pillars on base; encapsulate 1.6 mm PCB in the top block
    Per maintainer:
    - Centre the pillars + grow module on the base depth (Y 190 -> 160); the LED stays
    directly over the plant (offset 0.0/0.0). Fill port moved to the front apron, clear
    of the now-centred insert.
    - Encapsulate the controller+driver PCB INSIDE the top block: an internal bay at the
    right end (around the right pillar) with 4 standoff bosses; the board no longer hangs
    exposed under the bar. USB-C reaches the outside through a port in the block rear face.
    The block prints in two parts (body + bottom lid) to install the board.
    - PCB is exactly 1.60 mm thick with 4 mounting holes (ver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
    [opencanopy_tabletop_pepper_v1_block_model.scad]
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2026-06-14 mechanical: grow light -> centered panel + heatsink (single mount); integrate WS2812B model
    Per maintainer + WI-PL-06:
    - Replace the slim LED bar with ONE centered LED grow PANEL (8×6 emitters across one board,
    ~300×210 mm, PL-06 fixture C) + a finned passive HEATSINK, on a SINGLE central mount under
    the top block (not a strip array). PL-06: a panel meets uniformity (>=0.6) at the 150 mm
    target clearance, where a bar needed >=200-225 mm (a taller unit) — the panel keeps the
    form short and centered. LED optical centre still over the plant (offset 0.0/0.0).
    - Integrate the electrical team's WS2812B-2020 vendor model for the 4 status LEDs: convert the
    provided STEP (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
    [opencanopy_tabletop_pepper_v1_block_model.scad]
2026-06-14 firmware: redesign for passive watering — remove the pump (ECO-003)
    Mechanical/electronics moved V1 to a two-pillar form with electronics in the
    top block and **passive self-watering** (reservoir + wick, no pump). The pump
    was the only watering actuator; firmware is rebuilt as monitor + warn. The grow
    LED is now the only actuator (the fan was already removed in ECO-001).
    control:
    - Remove the Pump HAL trait + MockPump, the INA219 pump-current I2C driver,
    pump_ml_per_sec from the calibration record (schema v3->v4; 28->24 bytes, old
    blobs fail the length check -> fail-safe), and the per-stage dosing setpoints.
    - irrigation_controller.rs -> moisture_monitor.rs: keep the sensor validator,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
    [app_state.rs, board.rs, calibration.rs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]
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

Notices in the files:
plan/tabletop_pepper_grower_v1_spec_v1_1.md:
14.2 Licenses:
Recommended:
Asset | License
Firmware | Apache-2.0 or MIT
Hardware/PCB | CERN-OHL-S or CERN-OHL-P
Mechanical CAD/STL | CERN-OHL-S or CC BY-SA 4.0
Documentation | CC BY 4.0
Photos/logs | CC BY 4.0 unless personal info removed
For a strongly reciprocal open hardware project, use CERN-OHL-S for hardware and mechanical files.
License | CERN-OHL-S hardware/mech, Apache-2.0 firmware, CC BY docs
